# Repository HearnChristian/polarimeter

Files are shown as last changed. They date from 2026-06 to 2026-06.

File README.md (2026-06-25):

# Polarimeter — Photodiode Analog Front-End

A 4-layer mixed-signal PCB that reads optical polarization by measuring the
photocurrent from a pair of photodiodes through a low-noise transimpedance
signal chain. Designed in KiCad; this repository contains the full schematic,
layout, fabrication outputs, and bill of materials.

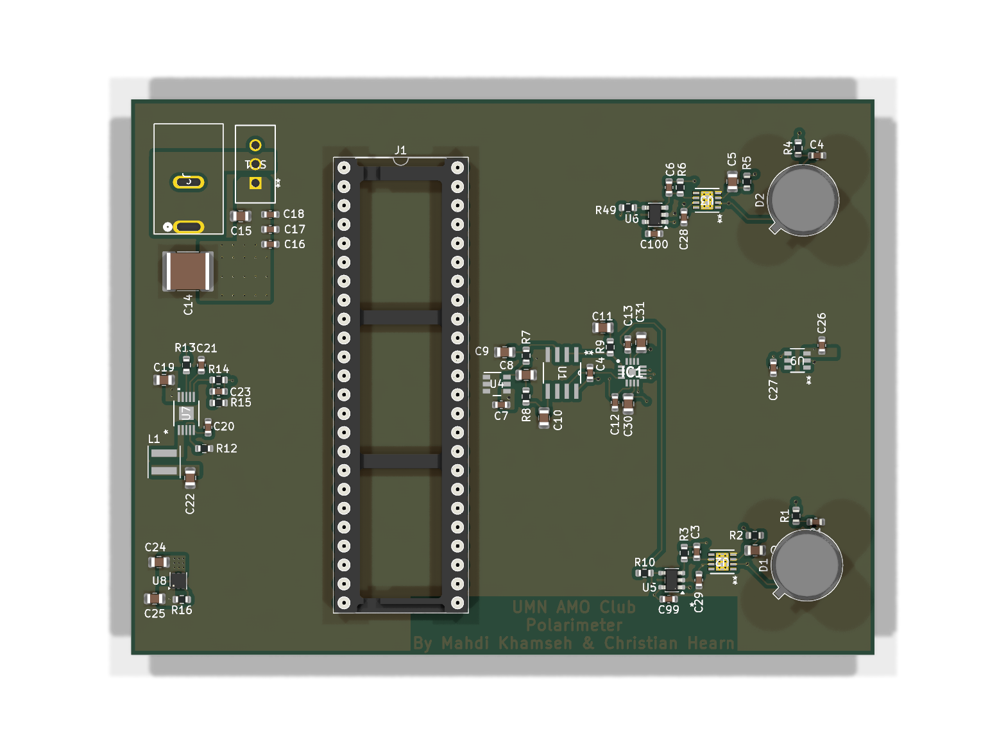
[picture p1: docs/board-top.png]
Board — top


📄 **[Full schematic (PDF)](docs/Polarimeter-schematic.pdf)** · 🖼️ [board bottom](docs/board-bottom.png)

## What it does

Light passing through a polarizing optical stage lands on two photodiodes
(`D1`, `D2`). Each diode's photocurrent is converted to a voltage by a
transimpedance amplifier (TIA), filtered, and buffered for acquisition. By
comparing the two channels, the relative polarization / intensity of the
incident beam can be recovered. The board carries its own low-noise power
regulation and a precision voltage reference so the analog measurement is clean
and ratiometric.

## Signal chain

| Stage | Part | Role |
|---|---|---|
| Photodiodes | `D1`, `D2` (TO-5) | Convert incident light to photocurrent |
| Transimpedance amps | OPA381 (precision, low-bias TIA) | I→V conversion of diode current |
| Gain / buffer | OPA320 / OPA2320 (low-noise, R-R CMOS) | Second-stage gain and buffering |
| Precision reference | REF3425 (2.5 V) | Stable ratiometric reference for the ADC path |
| Connector | 2×24 header (`J1`) + barrel jack (`J2`) | Signal breakout and DC input |

## Power

- **LT8609** synchronous step-down buck — primary rail regulation from the DC input jack.
- **LP5912-3.3** low-noise LDO — clean 3.3 V rail for the precision analog section.
- Local decoupling throughout (0.1 µF / 1 µF / 10 µF) to keep the TIA front-end quiet.

## Board

- **4 copper layers:** `F.Cu`, `In1.Cu`, `In2.Cu`, `B.Cu`
- Surface-mount construction, 0603/0805 passives
- Gerbers and drill files included for direct fabrication

## Repository layout

```
Polarimeter.kicad_pro      KiCad project
Polarimeter.kicad_sch      Root schematic
Power.kicad_sch            Power-supply sub-sheet (hierarchical)
Polarimeter.kicad_pcb      PCB layout (4-layer)
Polarimeter.csv            Bill of materials
Gerbers for AMO/           Fabrication outputs (Gerber + Excellon drill)
docs/                      Rendered schematic PDF + 3D board images
```

## Bill of materials

The full BOM lives in [`Polarimeter.csv`](Polarimeter.csv) (designator,
footprint, quantity, value). Key actives: OPA381, OPA320/OPA2320, REF3425,
LT8609, LP5912-3.3.

## Tools

Designed in [KiCad](https://www.kicad.org/). Open `Polarimeter.kicad_pro` to
view or edit the schematic and layout.

---

*Designed by Christian Hearn, with Malik Shaaban.*

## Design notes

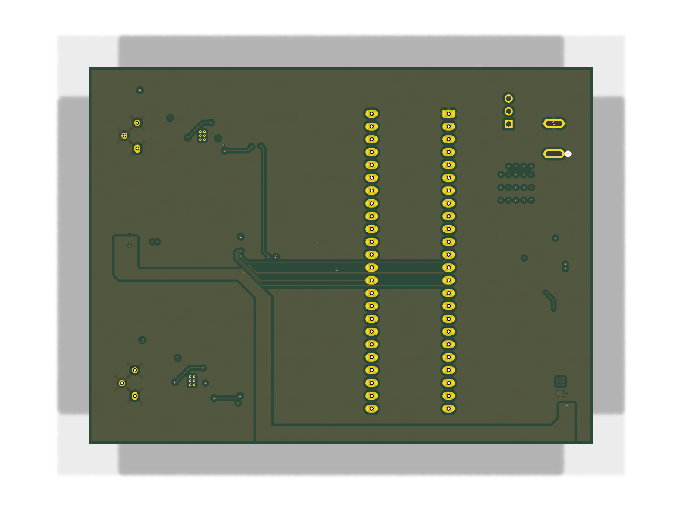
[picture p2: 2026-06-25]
docs/board-bottom.png

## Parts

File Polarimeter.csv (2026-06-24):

Id | Designator | Footprint | Quantity | Designation | Supplier and ref
1 | C12,C13 | C_0603_1608Metric | 2 | 3.3nF
2 | U5,U6 | SOT-23-5 | 2 | OPA320AIDBVR
3 | R16 | R_0603_1608Metric | 1 | 10k
4 | J1 | DIP-48_W15.24mm_Socket_LongPads | 1 | Conn_02x24_Counter_Clockwise
5 | R13,R5,R2 | R_0603_1608Metric | 3 | 100k
6 | C21,C18 | C_0603_1608Metric | 2 | 10n
7 | SW1 | TS01CQE_CNK | 1 | TS01CQE
8 | C17,C27,C16,C26,C1 | C_0603_1608Metric | 5 | 0.1u
9 | R14 | R_0603_1608Metric | 1 | 1M
10 | C5,C2 | C_0805_2012Metric | 2 | 0.1uF
11 | U8 | WSON-6-1EP_2x2mm_P0.65mm_EP1x1.6mm_ThermalVias | 1 | LP5912-3.3DRV
12 | R10,R49 | R_0603_1608Metric | 2 | 49
13 | C11 | C_0805_2012Metric | 1 | 10 uF
14 | J2 | CONN_37AH | 1 | PJ-037AH
15 | C19 | C_0805_2012Metric | 1 | 4.7u
16 | C31,C30,C10,C9 | C_0805_2012Metric | 4 | 1 uF
17 | U2,U3 | DRB8_2P4X1P65 | 2 | OPA381AIDRBT
18 | C25 | C_0805_2012Metric | 1 | v
19 | C6,C3 | C_0603_1608Metric | 2 | 24.7pF
20 | R12 | R_0603_1608Metric | 1 | 18.2 kOhms
21 | U1 | D8 | 1 | OPA2320AID
22 | R7,R4,R1,R8 | R_0603_1608Metric | 4 | 1k
23 | C99,C29,C4,C100,C4,C28 | C_0603_1608Metric | 6 | 0.1uF
24 | R9 | R_0603_1608Metric | 1 | 0.1
25 | U4 | DBV0006A_N | 1 | REF3425IDBVR
26 | U7 | 05-08-1664_ADI | 1 | LT8609EMSE-TRPBF
27 | C8 | C_0805_2012Metric | 1 | 10uF
28 | C15 | C_0805_2012Metric | 1 | 10u
29 | D1,D2 | TO-5-3 | 2 | D_Photo
30 | L1 | L_Coilcraft_XxL4020 | 1 | 2.2u
31 | C7 | C_0603_1608Metric | 1 | 0.1 uF
32 | C22 | C_0805_2012Metric | 1 | 22u
33 | R15 | R_0603_1608Metric | 1 | 187k
34 | U9 | UJ_6_ADI | 1 | ADR130AUJZ-REEL7
35 | C24 | C_0805_2012Metric | 1 | 1u
36 | C14 | C_2220_5750Metric | 1 | 47u
37 | C20 | C_0603_1608Metric | 1 | 1u
38 | IC1 | QFN50P300X300X80-17N-D | 1 | ADS8355IRTET
39 | R3,R6 | R_0603_1608Metric | 2 | 787
40 | C23 | C_0603_1608Metric | 1 | 10p

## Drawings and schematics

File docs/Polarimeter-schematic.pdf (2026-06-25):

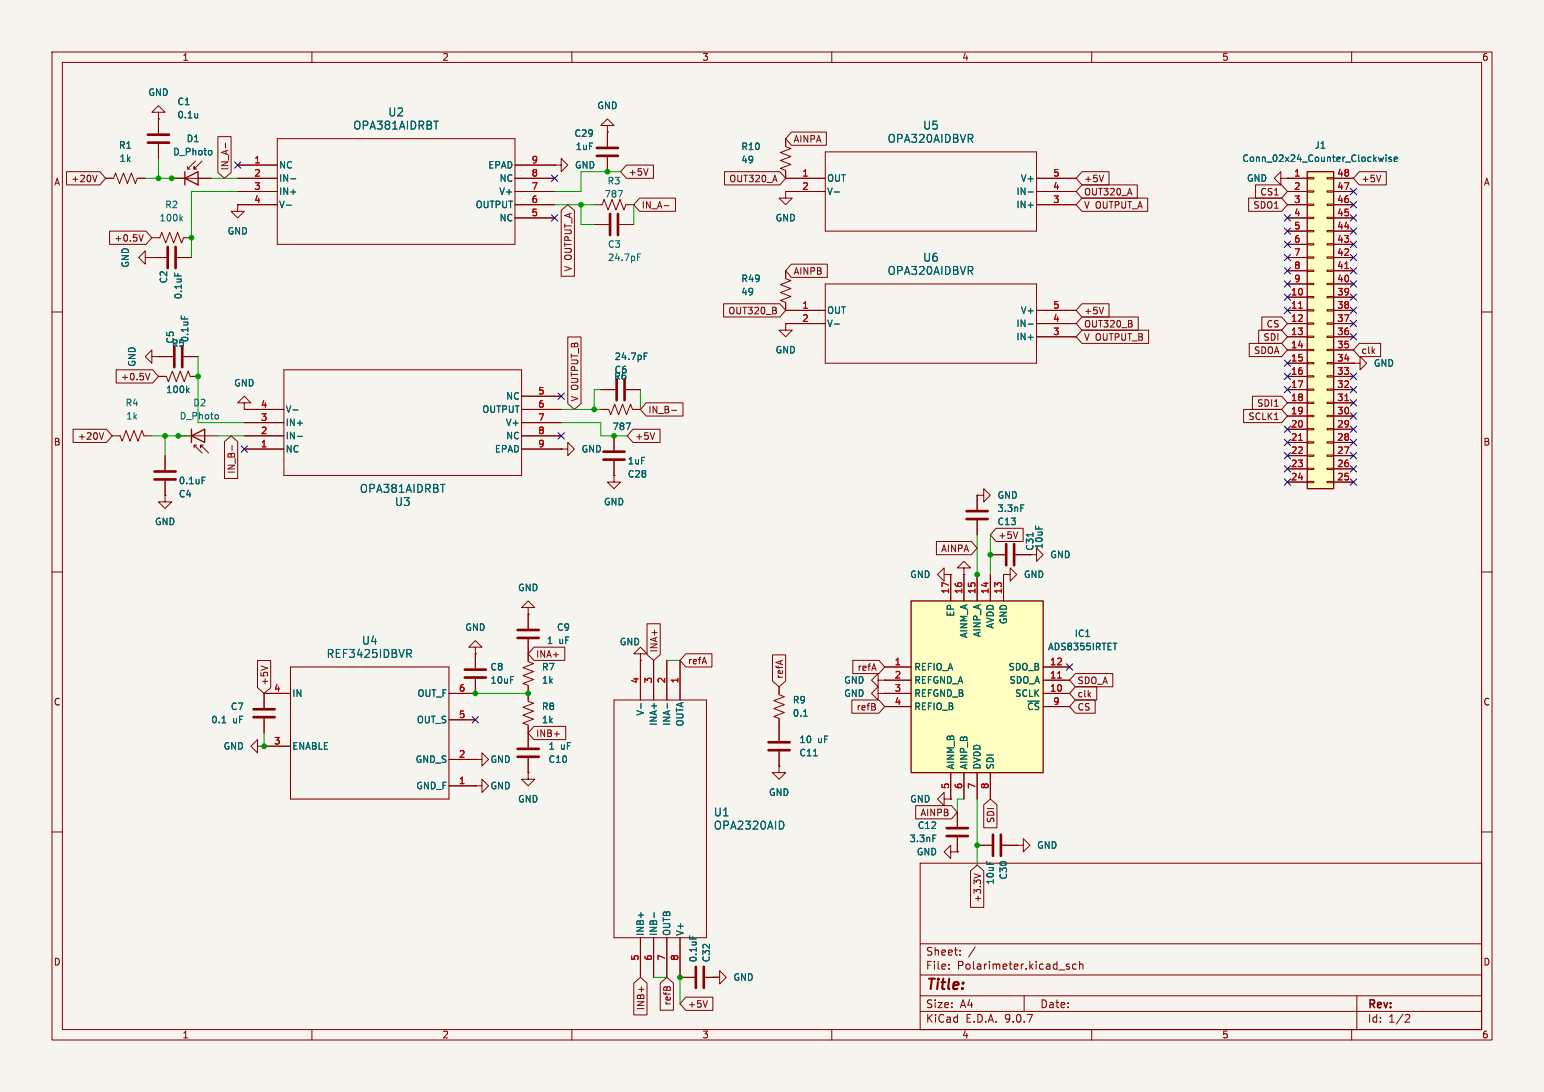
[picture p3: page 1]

7 AVDD 14 SDI 8 GND 13 SDO_B 12 SDO_A 11 SCLK 10 ~{CS} 9 GND C30 10uF GND U1 OPA2320AID OUTA

7 AVDD 14 SDI 8 GND 13 SDO_B 12 SDO_A 11 SCLK 10 ~{CS} 9

Id: 1/2 Title: File: Polarimeter.kicad_sch Sheet: /

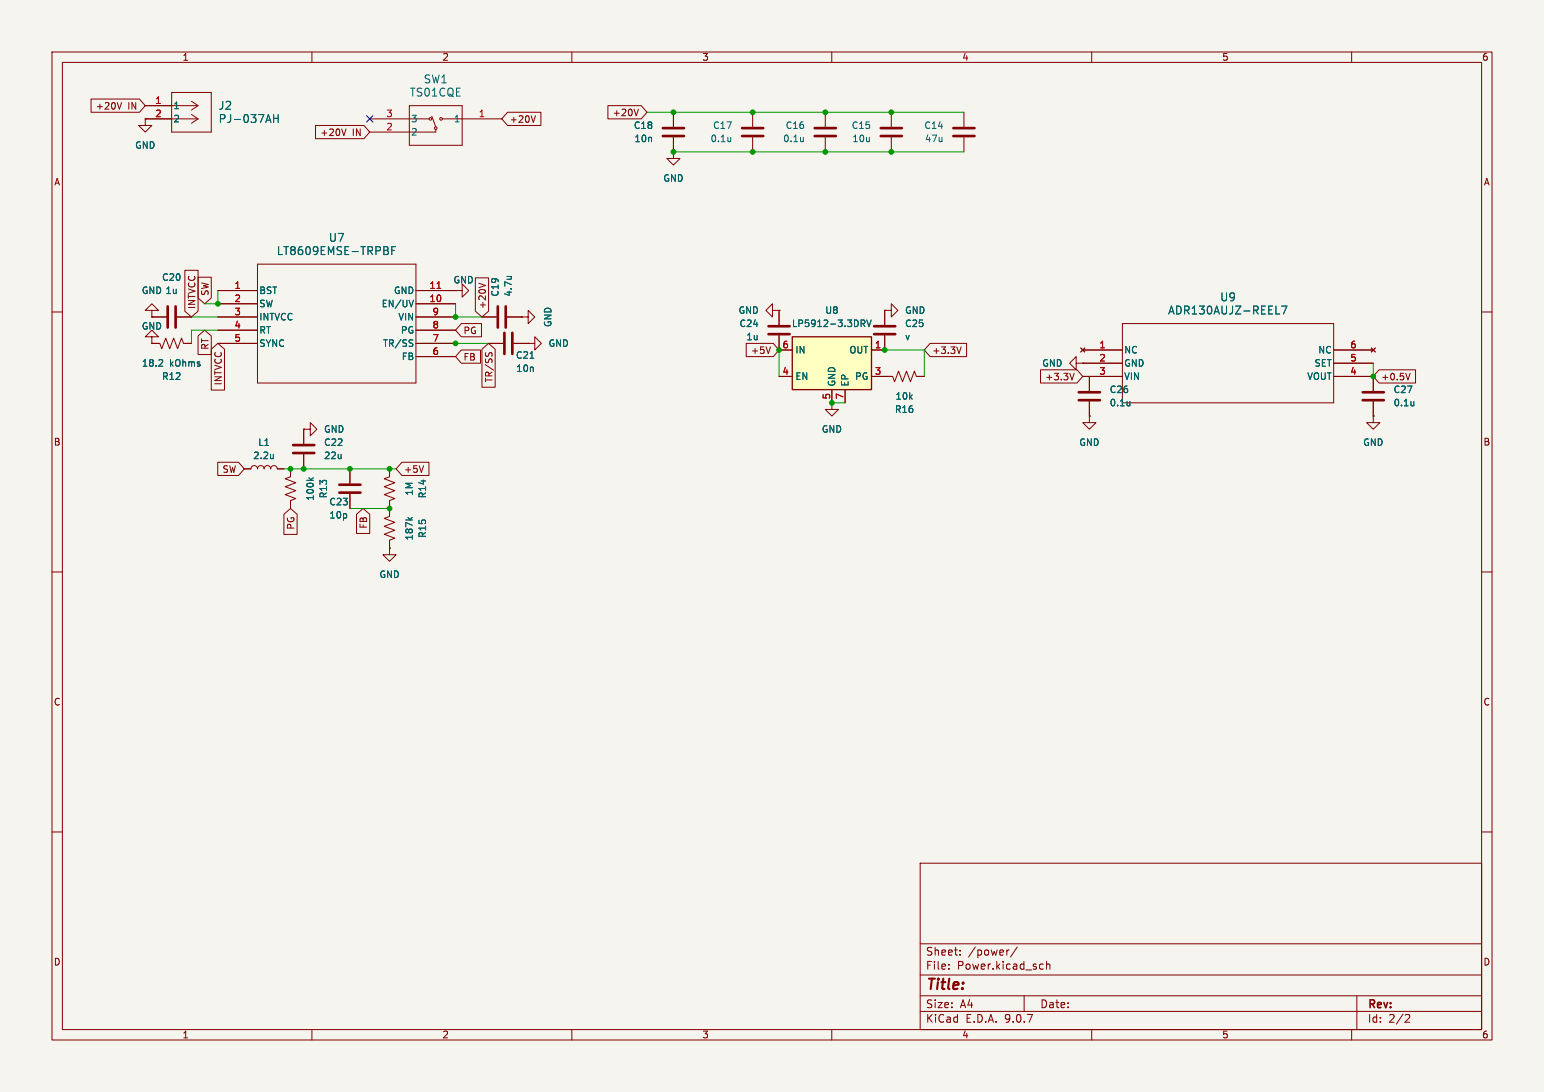
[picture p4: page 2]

Id: 2/2 Title: File: Power.kicad_sch Sheet: /power/

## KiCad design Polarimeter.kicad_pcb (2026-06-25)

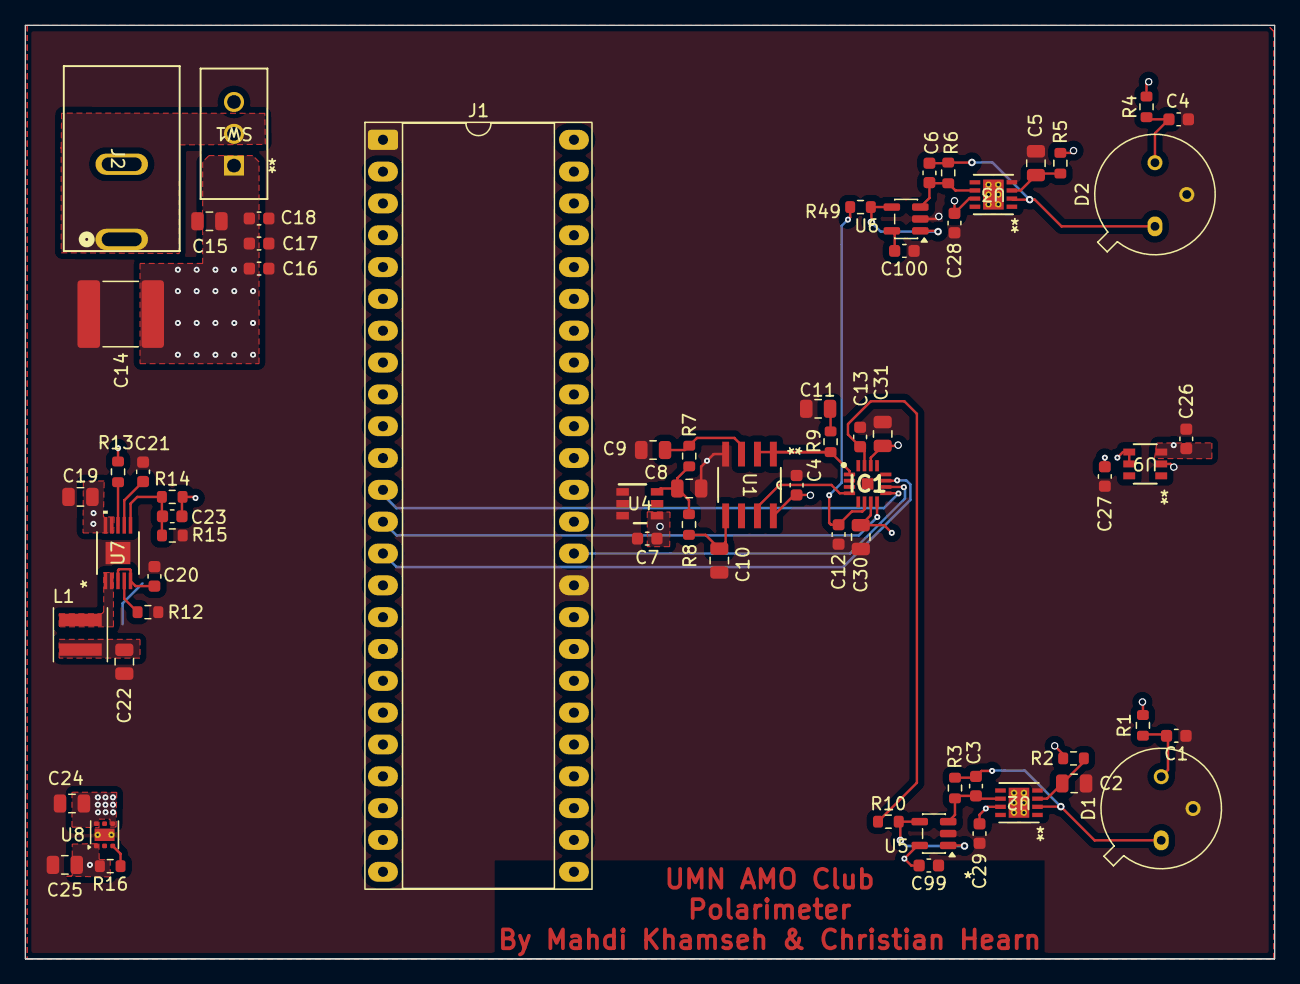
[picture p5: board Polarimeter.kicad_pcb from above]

Board: 4 copper layers, 99.7 x 74.5 mm, 66 parts (0 on the bottom side), 34 nets.

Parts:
C1, C16, C17, C26, C27: 0.1u; C_0603_1608Metric
C2, C5: 0.1uF; C_0805_2012Metric
C3, C6: 24.7pF; C_0603_1608Metric
C4, C4#2, C28, C29, C99, C100: 0.1uF; C_0603_1608Metric
C7: 0.1 uF; C_0603_1608Metric
C8: 10uF; C_0805_2012Metric
C9, C10, C30, C31: 1 uF; C_0805_2012Metric
C11: 10 uF; C_0805_2012Metric
C12, C13: 3.3nF; C_0603_1608Metric
C14: 47u; C_2220_5750Metric
C15: 10u; C_0805_2012Metric
C18, C21: 10n; C_0603_1608Metric
C19: 4.7u; C_0805_2012Metric
C20: 1u; C_0603_1608Metric
C22: 22u; C_0805_2012Metric
C23: 10p; C_0603_1608Metric
C24: 1u; C_0805_2012Metric
C25: v; C_0805_2012Metric
D1, D2: D_Photo; TO-5-3
IC1: ADS8355IRTET; QFN50P300X300X80-17N-D
J1: Conn_02x24_Counter_Clockwise; DIP-48_W15.24mm_Socket_LongPads
J2: PJ-037AH; CONN_37AH
L1: 2.2u; L_Coilcraft_XxL4020
R1, R4, R7, R8: 1k; R_0603_1608Metric
R2, R5, R13: 100k; R_0603_1608Metric
R3, R6: 787; R_0603_1608Metric
R9: 0.1; R_0603_1608Metric
R10, R49: 49; R_0603_1608Metric
R12: 18.2 kOhms; R_0603_1608Metric
R14: 1M; R_0603_1608Metric
R15: 187k; R_0603_1608Metric
R16: 10k; R_0603_1608Metric
SW1: TS01CQE; TS01CQE_CNK
U1: OPA2320AID; D8
U2, U3: OPA381AIDRBT; DRB8_2P4X1P65
U4: REF3425IDBVR; DBV0006A_N
U5, U6: OPA320AIDBVR; SOT-23-5
U7: LT8609EMSE-TRPBF; 05-08-1664_ADI
U8: LP5912-3.3DRV; WSON-6-1EP_2x2mm_P0.65mm_EP1x1.6mm_ThermalVias
U9: ADR130AUJZ-REEL7; UJ_6_ADI

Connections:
+0.5V: C27.1, R2.1, R5.1, U9.4 (VOUT), U9.5 (SET)
+3.3V: C25.2, C26.1, C30.1, IC1.7 (DVDD), R16.2, U8.1 (OUT), U9.3 (VIN)
+5V: C4.2, C7.2, C22.2, C23.1, C24.1, C28.1, C29.1, C31.1, C99.2, C100.2, IC1.14 (AVDD), J1.48, L1.2, R13.2, R14.2, U1.8 (V+), U2.7 (V+), U3.7 (V+), U4.4 (IN), U5.5 (V+), U6.5 (V+), U8.4 (EN), U8.6 (IN)
+20V: C14.1, C15.1, C16.1, C17.1, C18.1, C19.2, R1.1, R4.1, SW1.1, U7.9 (VIN), U7.10 (EN/UV)
AINPA: C13.1, IC1.15 (AINP_A), R10.1
AINPB: C12.1, IC1.6 (AINP_B), R49.1
CS: IC1.9 (~CS), J1.12
FB: C23.2, R14.1, R15.2, U7.6 (FB)
GND: C1.1, C2.1, C4.1, C4#2.1, C5.1, C7.1, C8.2, C9.2, C10.2, C11.2, C12.2, C13.2, C14.2, C15.2, C16.2, C17.2, C18.2, C19.1, C20.1, C21.2, C22.1, C24.2, C25.1, C26.2, C27.2, C28.2, C29.2, C30.2, C31.2, C99.1, C100.1, D1.2 (A), D2.2 (A), IC1.2 (REFGND_A), IC1.3 (REFGND_B), IC1.5 (AINM_B), IC1.13 (GND), IC1.16 (AINM_A), IC1.17 (EP), J1.1, J1.34, R12.1, R15.1, U1.4 (V-), U2.4 (V-), U2.9 (EPAD), U3.4 (V-), U3.9 (EPAD), U4.1 (GND_F), U4.2 (GND_S), U4.3 (ENABLE), U5.2 (V-), U6.2 (V-), U7.11 (GND), U8.5 (GND), U8.7 (EP), U9.2 (GND)
INA+: C9.1, R7.1, U1.3 (INA+)
INB+: C10.1, R8.1, U1.5 (INB+)
INTVCC: C20.2, U7.3 (INTVCC), U7.5 (SYNC)
IN_A-: C3.2, D1.1 (K), R3.2, U2.2 (IN-)
IN_B-: C6.2, D2.1 (K), R6.2, U3.2 (IN-)
unnamed: C11.1, R9.1
unnamed: C1.2, D1.3, R1.2
unnamed: C4#2.2, D2.3, R4.2
unnamed: C2.2, R2.2, U2.3 (IN+)
unnamed: C5.2, R5.2, U3.3 (IN+)
unnamed: C8.1, R7.2, R8.2, U4.6 (OUT_F)
unnamed: R16.1, U8.3 (PG)
OUT320_A: R10.2, U5.1 (OUT), U5.4 (IN-)
OUT320_B: R49.2, U6.1 (OUT), U6.4 (IN-)
PG: R13.1, U7.8 (PG)
RT: R12.2, U7.4 (RT)
SDI: IC1.8 (SDI), J1.13
SDOA: IC1.11 (SDO_A), J1.14
SW: L1.1, U7.1 (BST), U7.2 (SW)
TR/SS: C21.1, U7.7 (TR/SS)
V OUTPUT_A: C3.1, R3.1, U2.6 (OUTPUT), U5.3 (IN+)
V OUTPUT_B: C6.1, R6.1, U3.6 (OUTPUT), U6.3 (IN+)
clk: IC1.10 (SCLK), J1.35
refA: IC1.1 (REFIO_A), R9.2, U1.1 (OUTA), U1.2 (INA-)
refB: IC1.4 (REFIO_B), U1.6 (INB-), U1.7 (OUTB)

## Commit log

2026-06-24 Initial commit: Polarimeter photodiode analog front-end
    KiCad 4-layer mixed-signal board for optical polarization measurement.
    Includes schematic (hierarchical), PCB layout, fabrication gerbers/drill,
    and bill of materials.
    [Polarimeter-B_Cu.gbl, Polarimeter-B_Mask.gbs, Polarimeter-B_Paste.gbp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]
2026-06-25 Add rendered docs, clean up sheet naming
    - Export schematic PDF and top/bottom 3D board renders to docs/
    - Embed renders + schematic PDF link in README
    - Rename hierarchical sub-sheet untitled.kicad_sch -> Power.kicad_sch
    and update references in root schematic and PCB
    - Remove stale orphaned duplicate of the power sheet
    - Credit co-designer
    [Polarimeter.kicad_pcb, Polarimeter.kicad_sch, Power.kicad_sch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]
